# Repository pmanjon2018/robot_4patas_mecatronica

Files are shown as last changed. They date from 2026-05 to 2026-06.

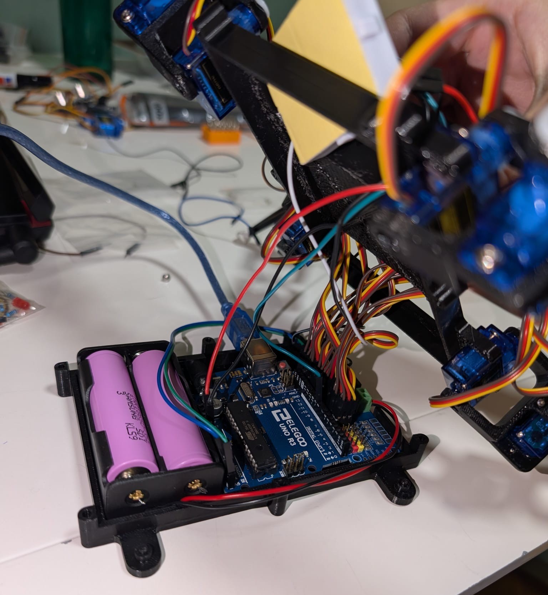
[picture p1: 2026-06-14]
Media/Fotos/MontajeVistaInteriorV2.JPG

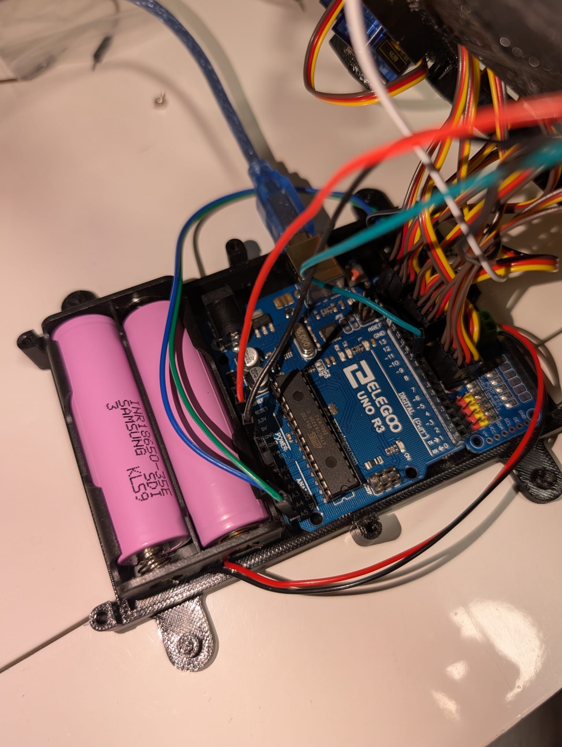
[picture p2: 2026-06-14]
Media/Fotos/MontajeInteriorPines.JPG

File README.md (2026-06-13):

# Robot Cuadrúpedo Autónomo 🤖

Este repositorio contiene la documentación técnica y el código fuente del proyecto final de **Robot con Patas** para la asignatura de **Mecatrónica**. En este trabajo se ha diseñado, fabricado, programado y validado experimentalmente un robot cuadrúpedo capaz de desplazarse de forma estable, transportar carga útil, realizar el seguimiento continuo de una pared y navegar autónomamente evadiendo obstáculos del entorno.

---

## 📋 Índice
1. [Descripción General](#-descripción-general)
2. [Objetivos Cumplidos](#-objetivos-cumplidos)
3. [Restricciones de Diseño](#-restricciones-de-diseño)
4. [Diseño y Arquitectura del Sistema](#-diseño-y-arquitectura-del-sistema)
5. [Problemas Encontrados y Soluciones Adoptadas](#-problemas-encontrados-y-soluciones-adoptadas)
6. [Modos de Funcionamiento](#-modos-de-funcionamiento)
7. [Pruebas de Validación y Criterios de Éxito](#-pruebas-de-validación-y-criterios-de-éxito)
8. [Estructura del Repositorio](#%EF%B8%8F-estructura-del-repositorio)
9. [Documentación Adjunta](#-documentación-adjunta)

---

## 🔍 Descripción General

El propósito central de este proyecto ha sido el desarrollo integral de un **robot con patas completamente funcional**, unificando conceptos avanzados de diseño mecánico, electrónica de control, programación embebida en tiempo real, sistemas de alimentación autónoma y verificación empírica.

La elección de una configuración **cuadrúpeda** responde a un compromiso de ingeniería: proporciona un equilibrio óptimo entre estabilidad estática y dinámica, control de la complejidad mecánica y versatilidad de maniobra en entornos donde los robots con ruedas presentan limitaciones. El resultado es un prototipo robótico autónomo, desvinculado de conexiones umbilicales de alimentación, dotado de una estructura de fabricación propia y una interfaz hombre-máquina (HMI) básica para la gestión segura del encendido y apagado del sistema.

---

## 🎯 Objetivos Cumplidos

A lo largo del desarrollo del proyecto, se lograron satisfacer satisfactoriamente los siguientes objetivos funcionales e hitos de ingeniería:

- [x] **Diseño y construcción:** Estructura física robusta, ligera y balanceada para un robot cuadrúpedo.
- [x] **Integración mecatrónica:** Acoplamiento óptimo de actuadores, sensórica de distancia, electrónica de control y sistemas de potencia.
- [x] **Locomoción guiada:** Implementación de algoritmos de marcha estables para el desplazamiento paralelo respecto a una pared de referencia.
- [x] **Capacidad de carga:** Capacidad probada de transporte de una carga muerta de **250 g** sobre una sección útil especificada de **5 cm x 5 cm**.
- [x] **Navegación inteligente:** Desarrollo de una lógica reactiva y autónoma para la evasión de obstáculos en tiempo real.
- [x] **Validación empírica:** Superación exitosa de pruebas experimentales en escenarios físicos controlados.

---

## ⚙️ Restricciones de Diseño

El prototipo final se consolidó respetando estrictamente el marco de restricciones técnicas y operativas del proyecto:

| Criterio | Restricción / Especificación Técnica |
| :--- | :--- |
| **Dimensiones Máximas** | Envolvente cúbica máxima de 30 cm de alto, 30 cm de ancho y 30 cm de profundidad. |
| **Alimentación** | 100% autónoma a bordo, implementada mediante el uso de baterías recargables. |
| **Aislamiento Eléctrico** | Ausencia absoluta de cables de alimentación o control externos hacia el entorno durante las pruebas. |
| **Estructura Portante** | Chasis y patas de fabricación propia, justificados técnicamente mediante selección de materiales y análisis funcional. |
| **Componentes Comerciales** | Permitidos exclusivamente para elementos genéricos de sensórica, actuación y placas de control. |
| **Interfaz de Usuario** | Inclusión obligatoria de un mecanismo básico de hardware para el arranque y la parada segura. |

---

## 🛠️ Diseño y Arquitectura del Sistema

El diseño mecánico de partida se basó en un modelo open source publicado en Thingiverse, concretamente el proyecto **“Spider robot (quad robot, quadruped)”**, un robot cuadrúpedo impreso en 3D y alimentado mediante Arduino [web:1]. A partir de esta referencia, se adaptaron distintos componentes con **Blender** para ajustarlos a los requisitos geométricos, estructurales y funcionales del proyecto [web:1].

Para simplificar las fases de diseño, manufactura y posterior integración mecatrónica, el robot se estructuró modularmente en los siguientes seis subsistemas interactuantes:

### 1. Estructura Mecánica
- **Componentes:** Chasis principal, soportes estructurales y eslabones de las patas.
- **Detalles:** Diseñados a medida y fabricados específicamente para este proyecto, optimizando la relación rigidez-peso y protegiendo los componentes electrónicos internos.

### 2. Sistema de Actuación
- **Componentes:** Servomotores o actuadores de alto torque distribuidos en las extremidades.
- **Detalles:** Responsables de ejecutar los patrones cinemáticos de las patas para la generación de la marcha (*gait*) y el mantenimiento del equilibrio dinámico.

### 3. Sensórica
- **Componentes:** Sensores de distancia y proximidad, como ultrasonido, infrarrojo o ToF.
- **Detalles:** Dispuestos para la detección lateral de paredes, el control de distancia en paralelo y la detección frontal de obstáculos en la trayectoria.

### 4. Control Embebido
- **Componentes:** Unidad de procesamiento central basada en microcontrolador o tarjeta de desarrollo embebida.
- **Detalles:** Encargada de la lógica de control en tiempo real, procesamiento de señales de sensores, coordinación de actuadores y gestión del comportamiento autónomo.

### 5. Alimentación y Potencia
- **Componentes:** Sistema de baterías recargables con pilas de 3.7V para la distribución de energía.
- **Detalles:** Garantiza el suministro estable del sistema, separando en la medida de lo posible la electrónica de control de la etapa de potencia de los motores.

### 6. Interfaz de Usuario
- **Componentes:** Botones físicos de interacción rápida y elementos visuales o sonoros de estado, como LEDs de diagnóstico.
- **Detalles:** Permite al operador inicializar las rutinas autónomas o inducir una parada controlada de forma inmediata.

> 💡 **Nota de ingeniería:** Esta división modular facilitó significativamente las tareas independientes de prueba, calibración de sensores, mantenimiento mecánico y aislamiento de errores de software y hardware.

---

## 🔧 Problemas Encontrados y Soluciones Adoptadas

Durante el desarrollo e integración del robot surgieron diversas incidencias mecánicas, electrónicas y de fabricación. La resolución de estos problemas fue fundamental para lograr una plataforma funcional y suficientemente robusta para las pruebas finales.

### 1. Problemas con las pilas recargables
Inicialmente se adquirieron pilas recargables que no incluían un cargador compatible, lo que impidió su uso inmediato en la fase de alimentación autónoma del sistema. Como solución, fue necesario comprar nuevas unidades y reorganizar temporalmente la estrategia de alimentación para continuar con el desarrollo.

### 2. Sensor de ultrasonidos averiado
Uno de los sensores de ultrasonidos dejó de funcionar correctamente durante la fase de integración, afectando a la fiabilidad de la detección de distancias. Para resolver esta incidencia, se sustituyó el sensor defectuoso y se recalibraron las lecturas del sistema.

### 3. Limitaciones en la impresión 3D
En una de las iteraciones de fabricación, algunas piezas impresas resultaron más pequeñas de lo esperado, lo que provocó problemas de acoplamiento y montaje. La solución consistió en revisar las dimensiones del diseño, modificar las medidas del modelo y volver a imprimir las piezas corregidas.

### 4. Mejora del giro en las articulaciones
Durante las pruebas se observó que ciertas articulaciones no giraban con la suavidad deseada, afectando a la calidad de la marcha. Para mejorar este comportamiento, se llevó a cabo una limpieza de los motores y un engrase de las zonas mecánicas con mayor fricción.

### 5. Motores averiados
Algunos motores se deterioraron o dejaron de responder correctamente tras varias sesiones de prueba. Fue necesario identificar las unidades dañadas, sustituirlas y volver a verificar el comportamiento de las patas afectadas.

### 6. Riesgo eléctrico por pilas defectuosas
En una fase del montaje, unas pilas defectuosas provocaron una situación de riesgo que estuvo cerca de dañar el Arduino. A partir de este incidente, se revisó completamente la alimentación del sistema, comprobando tensiones, conexiones y el estado real de las baterías antes de realizar nuevas pruebas.

### 7. Propuesta de mejora futura
Como mejora de diseño para futuras versiones, se plantea rediseñar el compartimento de alimentación para que las pilas sean más fáciles de extraer y sustituir. Esta modificación simplificaría el mantenimiento, la recarga y la seguridad general del sistema.

> 💡 **Lección de ingeniería:** Las incidencias encontradas pusieron de manifiesto la importancia de validar por separado la fabricación mecánica, la fiabilidad de la sensórica, el estado de los actuadores y la seguridad eléctrica antes de realizar ensayos completos del robot.

---

## 🕹️ Modos de Funcionamiento

El comportamiento global del robot está regido por una **Máquina de Estados Finitos (FSM)** programada para priorizar la estabilidad de la marcha, la seguridad del sistema y la repetibilidad del movimiento.

### Estados principales del sistema

- **Estado de reposo / espera:** El robot permanece detenido hasta recibir la orden de inicio mediante la interfaz física.
- **Estado de avance:** El robot ejecuta la marcha programada para desplazarse de forma controlada.
- **Estado de seguimiento de pared:** El sistema utiliza la sensórica lateral para mantener una distancia aproximadamente constante respecto a una pared de referencia.
- **Estado de detección de obstáculo:** Cuando se detecta un obstáculo en la trayectoria, se interrumpe el comportamiento de avance normal.
- **Estado de evasión:** El robot ejecuta una maniobra correctiva para esquivar el obstáculo y recuperar una trayectoria válida.
- **Estado de parada segura:** Ante una orden del usuario o una condición crítica, el sistema detiene progresivamente los actuadores para evitar movimientos bruscos o daños mecánicos.

### Lógica general de operación

La FSM se diseñó con una filosofía reactiva, permitiendo cambiar entre estados en función de las lecturas de los sensores y de las condiciones del entorno. Este enfoque facilita una implementación clara, depurable y adecuada para sistemas embebidos con recursos limitados.

---

## ✅ Pruebas de Validación y Criterios de Éxito

Con el fin de verificar el cumplimiento de los objetivos del proyecto, se realizaron diferentes pruebas experimentales sobre el prototipo final.

### 1. Prueba de desplazamiento estable
Se comprobó la capacidad del robot para avanzar de forma continua sin pérdidas significativas de equilibrio ni bloqueos mecánicos en las articulaciones.

### 2. Prueba de seguimiento de pared
Se validó el funcionamiento del sistema de sensórica lateral y del algoritmo de control asociado, verificando que el robot fuese capaz de desplazarse manteniendo una referencia lateral razonablemente constante.

### 3. Prueba de evasión de obstáculos
Se evaluó la respuesta del robot ante la presencia de obstáculos en su trayectoria, comprobando que detectaba el objeto y ejecutaba una maniobra correctiva sin intervención externa.

### 4. Prueba de carga útil
Se verificó que el robot era capaz de transportar una masa de **250 g** distribuida sobre una superficie útil de **5 cm x 5 cm**, manteniendo un comportamiento aceptable durante el desplazamiento.

### 5. Prueba de autonomía funcional
Se comprobó que el sistema era capaz de operar alimentado exclusivamente por baterías, sin depender de cables externos durante la ejecución de las pruebas.

### Criterios de éxito
Se consideró que la validación del sistema era satisfactoria cuando el robot:
- Se desplazaba de forma estable.
- Mantenía el seguimiento de pared.
- Detectaba y evitaba obstáculos.
- Soportaba la carga útil especificada.
- Funcionaba de forma autónoma con alimentación embarcada.

---

## 🗂️ Estructura del Repositorio

La organización del repositorio se ha planteado para separar claramente el código, la documentación y los recursos de diseño:

```bash
.
├── README.md
├── docs/
│   ├── memoria.pdf
│   ├── esquemas/
│   └── pruebas/
├── firmware/
│   ├── main.ino
│   ├── sensores/
│   ├── actuadores/
│   └── control/
├── hardware/
│   ├── diseno_3d/
│   ├── esquemas_electricos/
│   └── lista_componentes/
└── media/
    ├── imagenes/
    └── videos/
```

> **Nota:** La estructura exacta puede adaptarse en función de la evolución del proyecto y del material finalmente incorporado al repositorio.

---

## 📎 Documentación Adjunta

Este repositorio puede incluir la siguiente documentación complementaria para reforzar la trazabilidad técnica del proyecto:

- Memoria técnica completa del sistema.
- Planos, modelos y modificaciones de las piezas impresas en 3D.
- Esquemas eléctricos y de alimentación.
- Código fuente del control embebido.
- Fotografías del montaje final.
- Evidencias experimentales en vídeo o capturas de las pruebas realizadas.

---

## 👨‍🔧 Autor

Proyecto desarrollado como trabajo final para la asignatura de **Mecatrónica**, orientado al diseño, construcción, integración y validación de un **robot cuadrúpedo autónomo**.

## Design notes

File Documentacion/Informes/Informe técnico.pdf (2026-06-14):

# Informe técnico

## Índice

1. Diseño Conceptual
1.1. Definición del Problema y Objetivos
1.2. Alternativas de Locomoción y Justificación Cinemática
1.3. Materiales y Especificaciones Geométricas
1.4. Análisis Inicial de Viabilidad Física (Carga y Torque)
1.5. Arquitectura del Sistema (Cajas Negras)
2. Diseño Detallado
2.1. Arquitectura de Hardware y Mapeo de Pines
2.2. Aislamiento y Gestión de Energía (Tolerancia a Fallos)
2.3. Estabilidad Estática y Centro de Gravedad
3. Fabricación e Integración
3.1. Fabricación Aditiva y Ensamblaje Mecánico
3.2. Gestión de Riesgos y Resolución de Problemas (Troubleshooting)
3.3. Análisis de Costes (Presupuesto)
4. Programación y Simulación
4.1. Gemelo Digital y Simulación Cinemática (PyBullet)
4.2. Arquitectura de Software y Máquina de Estados
4.3. Algoritmo de Locomoción (Trot Gait)
4.4. Navegación Autónoma y Evasión de Obstáculos
4.4. Fase 2: Desarrollo y Propuesta de Navegación Autónoma

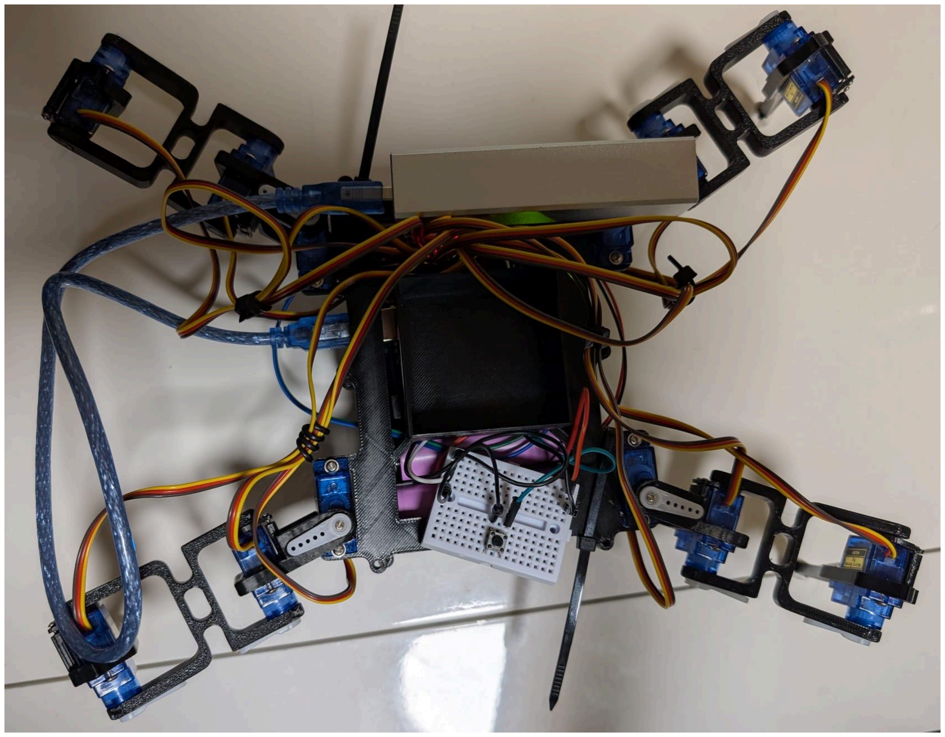
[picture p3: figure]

## 1. Diseño Conceptual

### 1.1. Definición del Problema y Objetivos

El objetivo fundamental del proyecto consiste en el diseño, desarrollo e integración de un sistema robótico cuadrúpedo completamente autónomo. El sistema debe resolver dos tareas operativas principales establecidas en los requerimientos:

1. Desplazamiento con carga: El robot debe desplazarse paralelo a una pared plana por al menos 1 metro de distancia en un tiempo máximo de 1 minuto. Durante esta tarea, debe transportar de manera estable una carga de 250 gramos ubicada en un área central específica de 5 cm x 5 cm sobre su estructura.
2. Evasión y Autonomía: El sistema debe navegar de forma autónoma esquivando obstáculos de 10x10 centímetros dentro de un área de 2 metros cuadrados, alcanzando cada una de las paredes colindantes partiendo desde el centro, en un tiempo máximo de 2 minutos.

### 1.2. Alternativas de Locomoción y Justificación Cinemática

Para cumplir con los criterios de estabilidad exigidos, se descartó el uso de ruedas o tracción por orugas en favor de un diseño biomimético de cuatro patas. Aunque la marcha básica de un cuadrúpedo puede lograrse con 8 grados de libertad (DOF), en este proyecto se ha optado por una arquitectura superior de 12 DOF (tres servomotores MG90S por pata: Coxa, Fémur y Tibia).

Esta decisión de diseño se justifica por tres ventajas mecánicas críticas para el éxito de la práctica:

- Gestión de la Carga Útil: Permite una mejor distribución del centro de masas y un control dinámico superior al transportar los 250 gramos de peso extra exigidos, manteniendo el polígono de sustentación.
- Eficiencia de Marcha: Facilita la implementación de un paso de trote coordinado, incrementando la velocidad para cumplir con las restricciones de tiempo establecidas.
- Evasión Activa: El motor de la cadera (Coxa) otorga al sistema la capacidad de pivotar y rotar sobre su propio eje central, un movimiento indispensable para la fase de evasión de obstáculos sin necesidad de arrastrar las extremidades.

### 1.3. Materiales y Especificaciones Geométricas

La estructura física del robot ha sido diseñada basándome en el conocido y pionero modelo de RegisHsu, pero adaptándolo de forma propia mediante software de modelado 3D: Blender + Phobos. No quería reinventar la rueda, sino ser práctica, aprender y aplicar los conocimientos adquiridos a lo largo de la carrera. Conservé el diseño de las patas y adapté el diseño del chasis a mis componentes y necesidades, como:

- Cerrar el agujero de la base del chasis
- Añadir una caja de carga para la masa de 5x5cm reforzada por debajo
- Cambiar el agujero de carga del arduino, pero no me fue útil porque decidí girarlo posteriormente.

- Redimensionar ambas partes del chasis para que entren mis componentes.

Las piezas estructurales (chasis y eslabones de las extremidades) están fabricadas en polímero PLA impreso en 3D, material que ofrece un equilibrio óptimo entre rigidez mecánica y ligereza.

El sistema presenta una envolvente compacta que cumple estrictamente con la restricción de no superar los 30 cm en ninguna de sus dimensiones:

- Cuerpo central (Chasis + Actuadores base): 13,5 cm de longitud x 12 cm de anchura x 3,3 cm de altura.
- Extremidades: Longitud máxima de extensión teórica de 16 cm. Altura nominal operativa de 10 cm con las articulaciones en ángulo recto (90°).

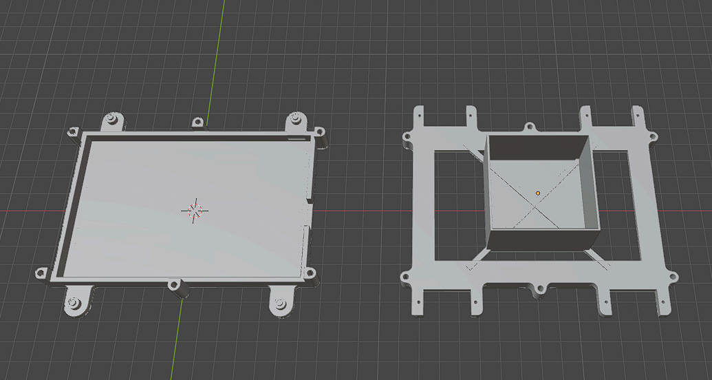
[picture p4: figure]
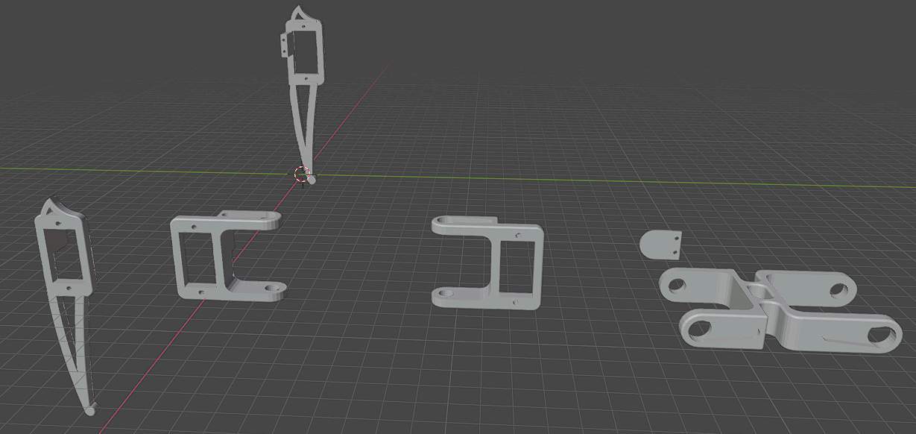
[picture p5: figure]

Figura 1: Diseño y componentes estructurales propios impresos en PLA.

### 1.4. Análisis Inicial de Viabilidad Física (Carga y Torque)

Tomando como base las especificaciones geométricas y el material seleccionado, se ha realizado un cálculo teórico de viabilidad de los actuadores (servomotores MG90S). El sistema completo es alimentado por baterías recargables, concretamente dos pilas 18650 de Litio que entregan una tensión nominal de 7.4V.

Estimando un brazo de palanca operativo de 5 cm (distancia desde el eje de articulación hasta el punto de apoyo en el suelo), cada pata tiene una capacidad teórica de elevación de aproximadamente 440 gramos. Durante un paso de trote, donde dos patas sostienen el peso total, la fuerza combinada es de 880 gramos. Considerando que la masa total estimada del sistema (chasis, baterías independientes, electrónica y el lastre obligatorio de 250 gramos) ronda los 800 gramos (exactamente 785 gramos), el diseño demuestra ser viable a nivel mecánico.

Posteriormente decidí que era mejor mover una pata por vez, lo que lo hace más estable con más peso, más robusto, no es más lento, y llega más lejos en menos tiempo.

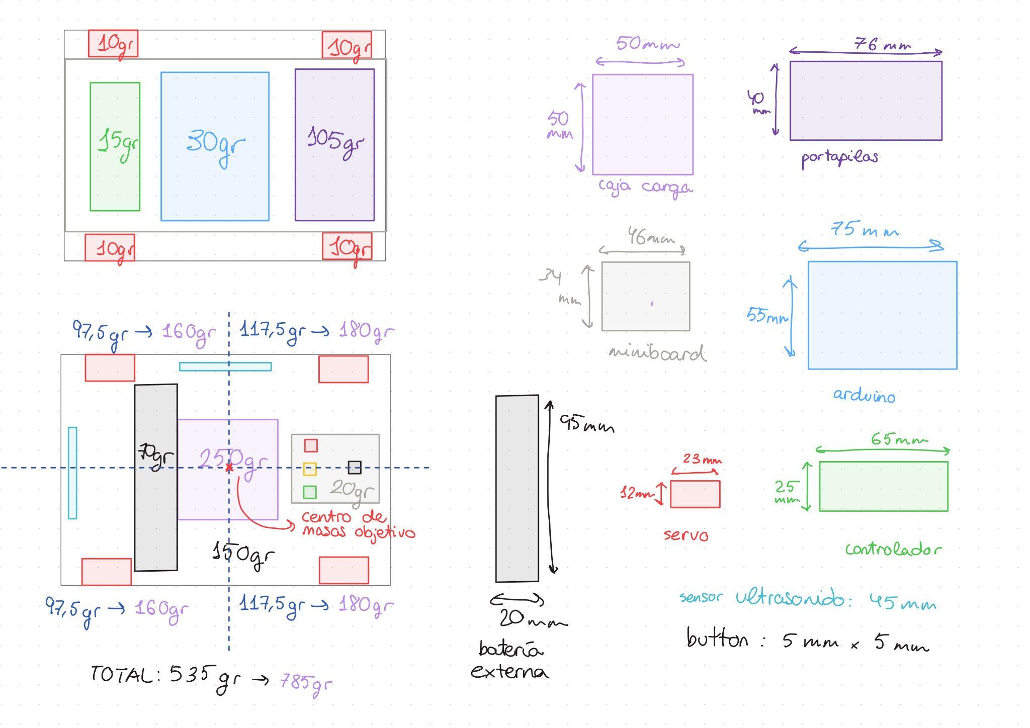
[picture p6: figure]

Figura 2: Boceto conceptual inicial indicando la distribución de masas, ubicación de la carga de 250g y sensores.

### 1.5. Arquitectura del Sistema (Cajas Negras)

El control del cuadrúpedo se divide funcionalmente en módulos interconectados, aislando la potencia de los actuadores de la lógica de control para garantizar la estabilidad eléctrica. Además, se integra una interfaz de usuario básica mediante pulsador físico e indicadores visuales para iniciar y detener el funcionamiento.

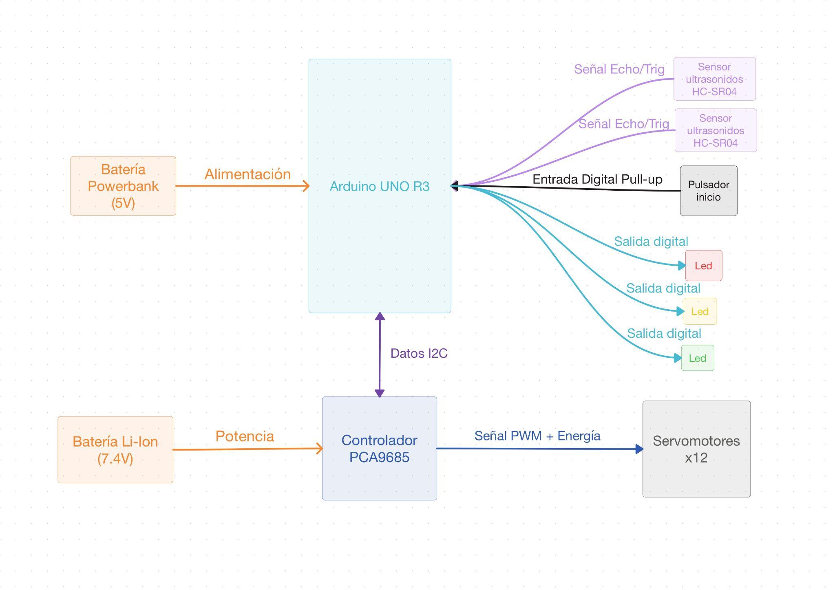
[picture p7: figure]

Figura 3: Diagrama de arquitectura de hardware del sistema.

## 2. Diseño Detallado

### 2.1. Arquitectura de Hardware y Mapeo de Pines

La integración de los componentes electrónicos se ha planificado priorizando la eficiencia del microcontrolador principal (Arduino UNO). Para evitar la saturación de los temporizadores internos del Arduino, se delegó el control de las señales PWM de los 12 motores MG90S a un controlador dedicado PCA9685, el cual se comunica mediante el protocolo I2C utilizando únicamente dos líneas de datos.

El mapeo de conexiones quedó establecido de la siguiente manera:

- Comunicación I2C (PCA9685): Pin analógico A4 (SDA) para los datos y A5 (SCL) para la señal de reloj.
- Sensores Ultrasónicos HC-SR04: Asignado a los pines digitales (uno analógico y uno digital) correspondientes para las señales Trigger y Echo, permitiendo la detección de obstáculos frontales y laterales, apra saber cuando pasamos el obstáculo.
- Interfaz Visual (Semáforo LED): Conectados a pines digitales configurados como salidas (OUTPUT) para indicar los estados de la máquina de estados (Reposo, Marcha, Alerta).
- Pulsador de Inicio/Parada: Conectado a un pin digital configurado por software como INPUT_PULLUP. Esta decisión de diseño permite utilizar la resistencia interna de 20k ohmios del microcontrolador, ahorrando componentes externos en la placa y evitando lecturas erróneas por estados flotantes (ruido eléctrico).

### 2.2. Aislamiento y Gestión de Energía (Tolerancia a Fallos)

Durante la fase inicial de pruebas se detectó una vulnerabilidad crítica: alimentar la lógica de control y la potencia de los actuadores desde una única fuente (baterías Li-Ion de 7.4V pasadas por el pin VIN del Arduino) provocaba picos de consumo masivos al arrancar los 12 motores simultáneamente. Esto causó una caída de tensión severa y sobrecalentó (quemó) el regulador de voltaje interno del microcontrolador, teniendo que comprar otro Arduino.

Aplicando el método científico para la resolución de problemas, la arquitectura final implementa un aislamiento galvánico y energético total:

1. Red de Potencia (Fuerza): El bloque de baterías 18650 (7.4V) se conecta directa y exclusivamente a la bornera de alimentación del PCA9685, entregando todo el amperaje necesario a los motores sin pasar por la placa lógica.
2. Red Lógica (Cerebro): El Arduino y sus sensores periféricos se alimentan de forma completamente independiente mediante un Powerbank de 5V conectado por USB. Esto garantiza que el "cerebro" nunca se apague ni sufra interferencias, sin importar cuánto esfuerzo mecánico estén realizando las patas.

Consideré que este modelo era más estable y mantenible, no corrí más riesgos de los necesarios.

### 2.3. Estabilidad Estática y Centro de Gravedad

Con un peso en vacío de 535 g, la distribución de componentes internos se modeló para alojar el requerimiento de los 250 g de carga extra sin comprometer la locomoción. Es verdad que sobrepasa un poco el peso de la parte posterior frente a la delantera, pero no es tan significante en la práctica. Las baterías 18650 (el componente más pesado del sistema) se han posicionado estratégicamente compensando el peso de la lógica de control, buscando que el Centro de Gravedad (CG) del sistema coincida con el cruce diagonal geométrico de las extremidades. La carga útil de 5x5 cm se asienta directamente sobre la vertical de este CG para prevenir momentos de vuelco hacia atrás durante el levantamiento de las patas delanteras.

## 3. Fabricación e Integración

### 3.1. Fabricación Aditiva y Ensamblaje Mecánico

La materialización del chasis y las extremidades se llevó a cabo mediante técnicas de prototipado rápido (Impresión 3D). Se utilizó un rollo de filamento PLA, consumiendo aproximadamente un 40% del material (equivalente a unos 7-10 € de coste de material neto), tuve que imprimir dos veces por problemas de redimensionamiento.

El ensamblaje mecánico requirió un ajuste fino (lijado) de las tolerancias en las articulaciones para asegurar que los ejes de los servomotores MG90S encajaran firmemente sin generar fricción parasitaria en las extremidades. Todo el cableado de potencia y datos se enrutó por el interior del chasis impreso para evitar enredos durante la marcha cuadrúpeda, pasando por los agujeros superiores que se dejaron en el diseño y proteger las conexiones ante posibles vuelcos.

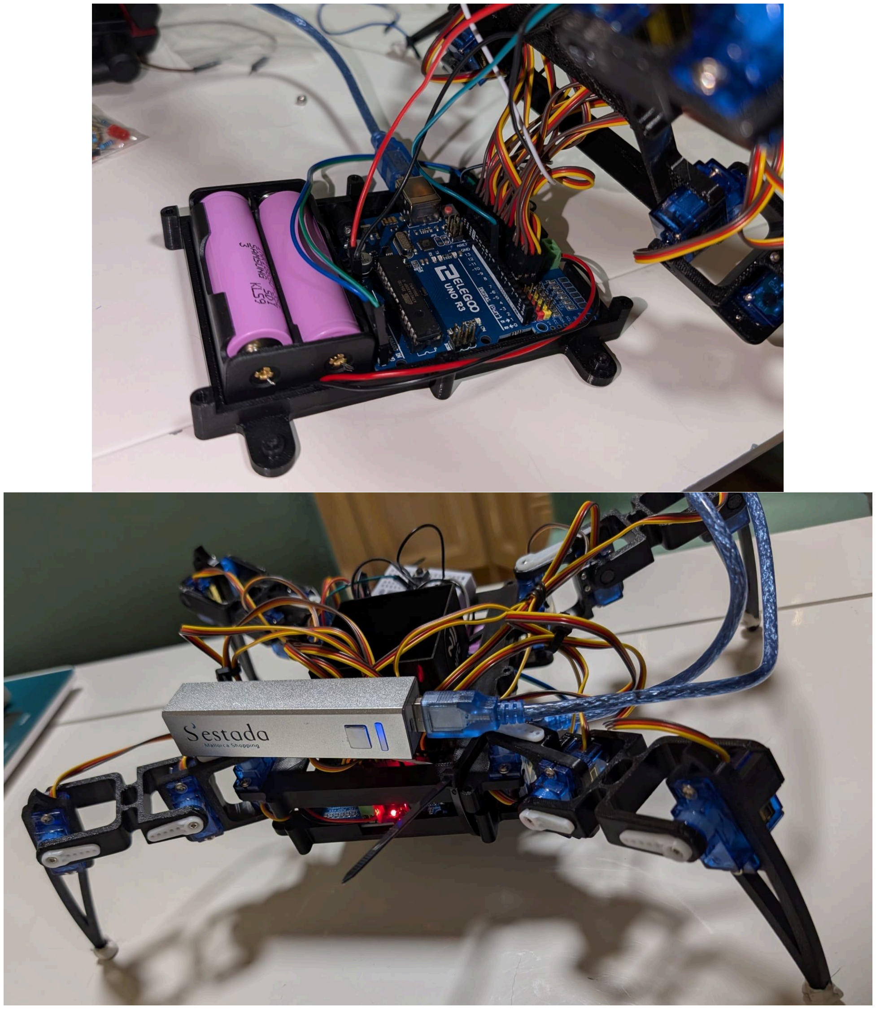
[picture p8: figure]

Figura 4: Integración del hardware en el chasis de PLA, mostrando el
aislamiento de la lógica y la potencia.

### 3.2. Gestión de Riesgos y Resolución de Problemas (Troubleshooting)

Durante la fase de integración física y primeras pruebas de estrés, el sistema sufrió varias contingencias propias del desarrollo de hardware en el mundo real, las cuales fueron documentadas y solventadas:

- Fallo de Regulación (Sobretensión): El intento inicial de alimentar la placa lógica y los actuadores simultáneamente con baterías Li-Ion provocó la quema del regulador de voltaje interno del Arduino UNO. Esto derivó en el rediseño inmediato de la arquitectura de energía (explicado en la sección 2.2) y la sustitución de la placa microcontroladora.

- Componentes Defectuosos de Fábrica (DOA): Se detectó un fallo de comunicación I2C derivado de un controlador PCA9685 defectuoso de fábrica, así como lecturas erráticas en uno de los sensores ultrasónicos HC-SR04, procediendo a su reemplazo pero no a tiempo.
- Fatiga Mecánica de Actuadores: El peso del robot (535 g) sumado a la carga útil estática (250 g) y las pruebas de potencia, generó picos de torque que estropearon la piñoneria interna de algunos servomotores durante la fase de calibración de la marcha. Para garantizar la fiabilidad el día de la prueba final, se amplió el margen de repuestos a 18 unidades totales.

### 3.3. Análisis de Costes (Presupuesto)

A continuación, se detalla el Bill of Materials (BOM) del proyecto. Se desglosa el coste ideal teórico del prototipo final frente al coste real de desarrollo, el cual incluye las mermas, repuestos y herramientas de alimentación adquiridas para solventar las incidencias descritas.

Componente | Cantidad Ideal | Coste de Desarrollo (Real) | Notas de Integración
Microcontrolador Arduino UNO | 1 | 7,00 € | Sustitución por quema del regulador original.
Controlador I2C PCA9685 | 1 | 7,00 € | Incluye gestión de 1 unidad defectuosa (devuelta).
Servomotores MG90S | 12 | 24,50 € | Adquisición de 18 uds por rotura mecánica en pruebas.
Sensor Ultrasónico HC-SR04 | 2 | 3,00 € | 3 uds totales adquiridas por defectos de fábrica.
Sistema de Energía Lógica (Powerbank 5V) | 1 | 0,00 € | Material amortizado / Regalo.
Sistema de Energía Potencia (Pilas 18650) | 2 | 50,00 € | Incluye pack de 10 celdas extra y cargador dedicado.
Portapilas 18650 | 1 | 2,00 € | Montaje en chasis central.
Material Estructural (PLA Impresión 3D) | ~150g | 8,50 € | Estimación del porcentaje de rollo de 20€ utilizado.
Componentes Pasivos (LEDs, Botón, Cables) | Varios | 0,00 € | Reutilización de stock de laboratorio / kits previos.
TOTAL PROYECTO REAL | | 102,00 € | Coste asumido para garantizar redundancia y repuestos.

# 4. Programación y Simulación

### 4.1. Gemelo Digital y Simulación Cinemática (PyBullet)

Antes de volcar el código al hardware físico y arriesgar la integridad de los actuadores, se desarrolló un entorno de simulación utilizando el motor de físicas PyBullet en Python. Se generó un archivo URDF (Unified Robot Description Format) modelando las masas exactas del chasis, las baterías y la carga útil de 250 g.

Para validar la viabilidad mecánica, se limitó la fuerza de las articulaciones virtuales a 0.215 N·m (el equivalente físico del torque máximo de los motores MG90S operando a 6-7V). La simulación confirmó que, implementando una marcha de trote, el robot es capaz de levantar la carga sin colapsar, amortiguando correctamente el impacto contra el suelo virtual.

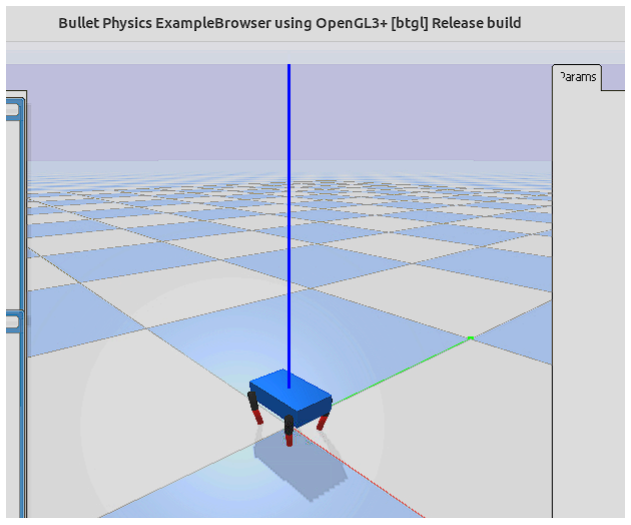
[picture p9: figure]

Figura 5: Simulación física del cuadrúpedo en PyBullet analizando el reparto de masas y límites de torque.

### 4.2. Arquitectura de Software y Máquina de Estados

El código del microcontrolador Arduino ha sido estructurado mediante una Máquina de Estados Finitos (FSM) no bloqueante. Esto permite que el robot pueda leer sensores y mover las patas al mismo tiempo sin quedarse "congelado" esperando una instrucción.

El sistema se divide en tres estados principales, indicados visualmente por el semáforo LED:

1. Estado de Reposo (LED Verde): Al pulsar el botón, el robot inicializa los 12 motores en su posición de 90 grados y entra en bucle de espera. Se aplica un sistema antirrebotes (debounce) por software de 250 ms en el pulsador para evitar lecturas falsas al iniciar la marcha.
2. Estado de Marcha (LED Verde): Al pulsar el botón, el robot inicia el desplazamiento autónomo en línea recta y el sensor ultrasónico comienza a emitir pulsos constantes.

3. Estado de Evasión/Parada (LED Amarillo o Rojo): Interrupción del ciclo de marcha dictada por la retroalimentación del entorno, si es un obstáculo evitable, el led se iluminará en amarillo, si es la pared, se iluminará en rojo.

### 4.3. Fase 1: Algoritmo básico de Locomoción

Para cumplir con el requisito de desplazamiento en línea recta transportando carga, se programó una cinemática de marcha tipo "Trote" (Trot Gait). En este ciclo, el robot mueve sus patas en pares diagonales (ej. delantera izquierda y trasera derecha simultáneamente). Este método garantiza que el Centro de Gravedad siempre se mantenga dentro del polígono de sustentación formado por las otras dos patas que permanecen en el suelo, maximizando la estabilidad durante el transporte de los 250 g.

### 4.4. Fase 2: Desarrollo y Propuesta de Navegación Autónoma

El enfoque principal y la validación empírica de este proyecto se han centrado en garantizar el éxito de la primera fase del requerimiento: la estabilidad mecánica y el desplazamiento continuo soportando la carga útil de 250 gramos.

No obstante, la arquitectura de software (Máquina de Estados) ha sido diseñada desde cero para soportar la Fase 2 (Evasión de Obstáculos). El código entregado en los anexos incluye la lógica de integración de los sensores ultrasónicos HC-SR04. La cinemática programada establece que, al detectar un obstáculo, el sistema interrumpa el trote y active un pivote lateral usando los actuadores de las Coxas. Debido a las incidencias de hardware con las lecturas erráticas de los sensores ultrasónicos iniciales y las limitaciones de tiempo físico para una calibración empírica segura, esta segunda fase se presenta a nivel de código y diseño conceptual, priorizando para la demostración física la robustez del requerimiento de carga.

# 5. Bibliografía

https://regishsu.blogspot.com/2015/07/robot-quadruped-robot-re-design-3-round.htmlhttps://www.thingiverse.com/thing:1009659https://www.instructables.com/DIY-Spider-R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

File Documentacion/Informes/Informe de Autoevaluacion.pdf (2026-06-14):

Grupo: Rocky

## Informe de Autoevaluación Individual

### 1. Reflexión sobre el Desarrollo Técnico

El desarrollo de este proyecto ha supuesto un reto de ingeniería multidisciplinar asumido de forma íntegramente individual. Esto ha puesto a prueba mi capacidad de resolución de problemas bajo presión en todas las áreas del diseño: modelado, impresión, electrónica y programación.

Inicialmente, sobreestimé la capacidad de diseño de otras personas, como fue coger el modelo pionero en cuadrúpedos de RegisHsu, en el cual confíe en su diseño de patas en 3 direcciones como hemos visto en varias asignaturas, que se ha replicado con leves modificaciones, pero que no es tan exacto para servomotores SG90, por lo que tuve que lijar las piezas de la cadera para que los motores pudiesen girar correctamente.

También subestimé el consumo eléctrico de 12 motores MG90S operando simultáneamente. Esto derivó en la necesidad de un cargador de pilas.

Además, al intentar hacerlo autónomo, el voltaje de las baterías directamente conectados al arduino que técnicamente tenía un regulador de entre 7.2V y 12V a 5V no funcionó, lo que derivó en un fallo crítico de hardware: sobrecalentamiento del regulador de voltaje, el cual se fundió, lo que me obligó a aplicar el método científico, aislar el problema y rediseñar la arquitectura hacia un sistema de energía de doble fuente, en este caso con una powerbank que no fuese muy pesada que le diese 5V por USB.

Esta crisis fue mi mayor aprendizaje: comprender la diferencia entre la teoría de un circuito en papel y la realidad física de la corriente.

### 2. Resiliencia Mecánica y Gestión del Alcance

A lo largo de las pruebas, tuve que hacer frente a la fatiga de los componentes, llegando a abrir y reparar manualmente la piñonería interna de los servomotores para no paralizar el desarrollo.

Asimismo, ante la recepción de sensores ultrasónicos defectuosos, tomé una decisión analítica de gestión de proyecto: congelar el alcance de la Fase 2 (Navegación Autónoma) para asegurar la Fase 1. Prioricé entregar un sistema físico robusto, capaz de transportar la carga con estabilidad, dejando la evasión de obstáculos implementada a nivel de código como una arquitectura preparada para el futuro.

### 3. Valoración Final

Considero que el resultado final es un éxito a nivel de diseño de sistemas. He logrado construir un gemelo digital en PyBullet para validar cálculos de torque, diseñar la estructura 3D basándome en otras que ya existían (no reinventar la rueda) y montar un hardware tolerante a fallos de forma autónoma. El proyecto demuestra madurez técnica, capacidad de reparación in-situ y una gestión de riesgos realista.

Como conclusión, me he encargado yo sola de hacer todo el proyecto. Ha sido un desafío, pero he aprendido mucho.

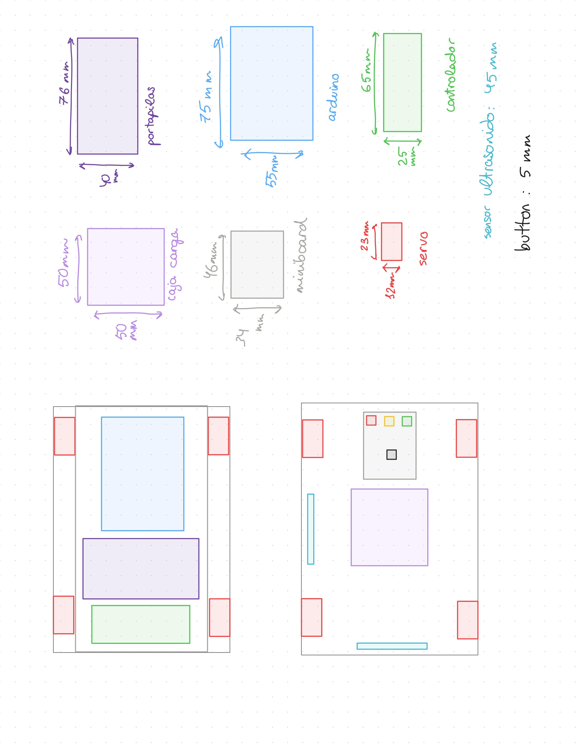
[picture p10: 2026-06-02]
Media/Fotos/ConceptRobot-V2.jpg

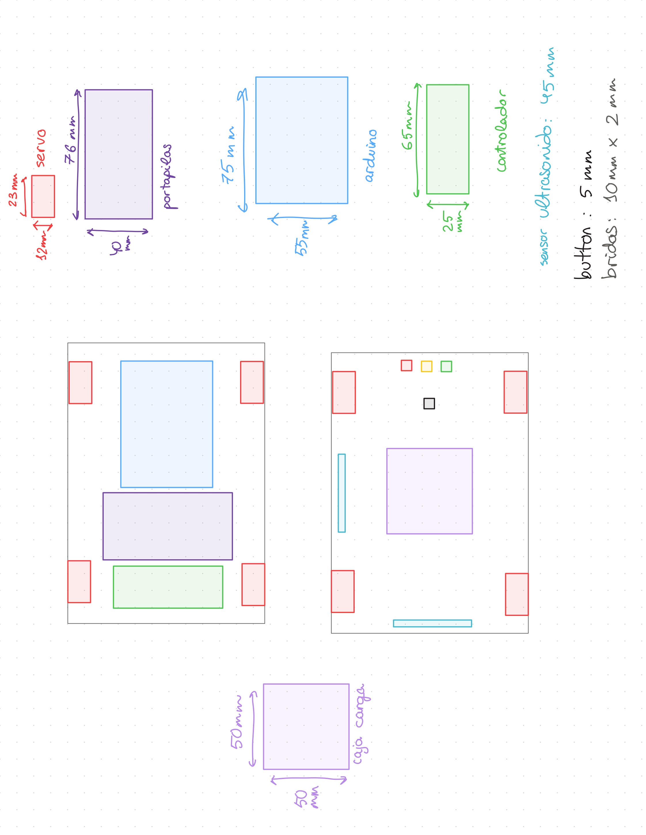
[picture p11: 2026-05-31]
Media/Fotos/ConceptRobot-V1.jpg

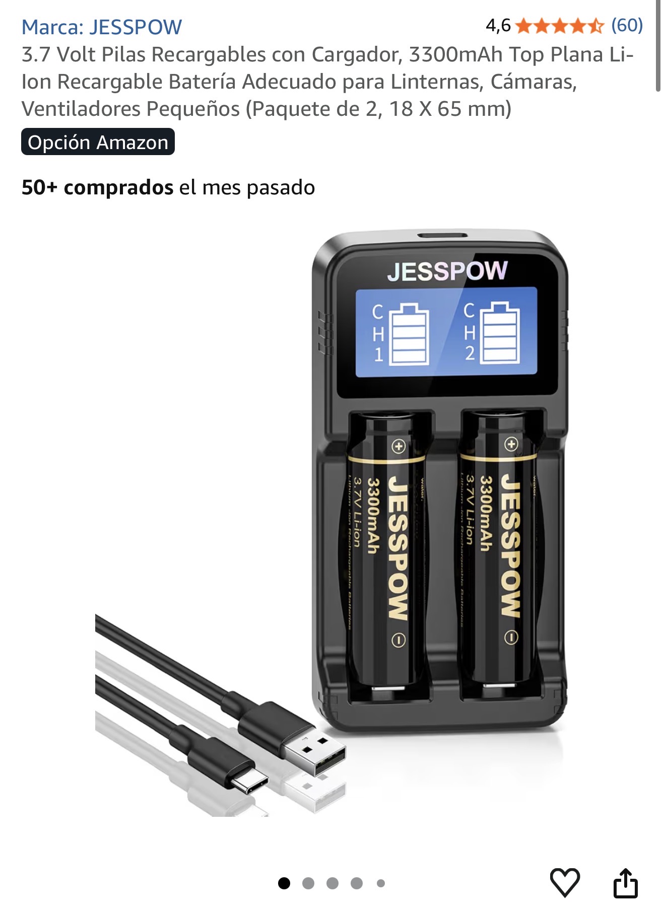
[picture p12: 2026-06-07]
Hardware/Electronica/PortaPilas.jpg

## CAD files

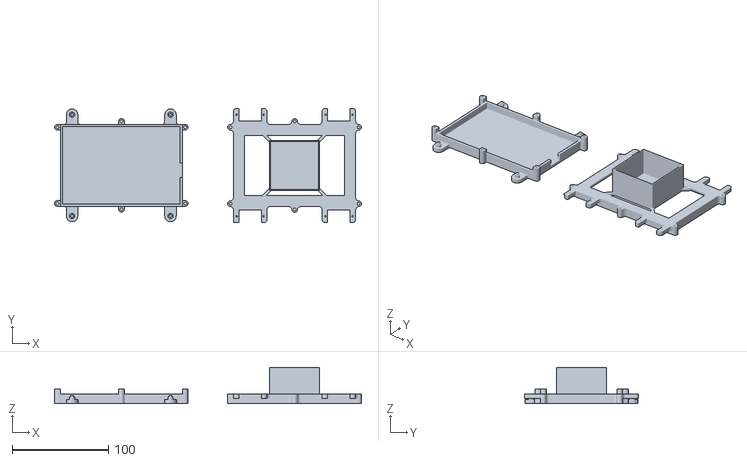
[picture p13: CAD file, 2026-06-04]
Hardware/ArchivosImpresion/body-v2.stl
318.9 x 118.5 x 37.5

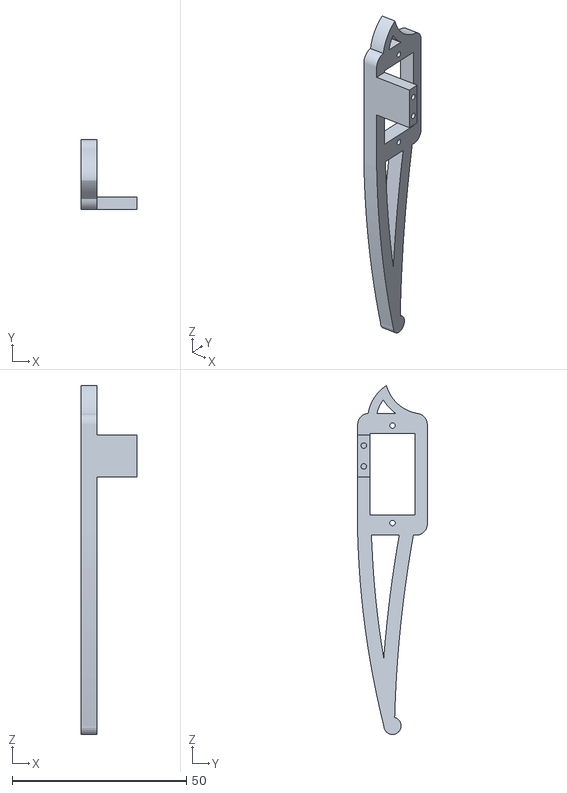
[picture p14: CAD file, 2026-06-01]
Hardware/ArchivosImpresion/tibia_r.stl
16.0 x 20.0 x 100.3

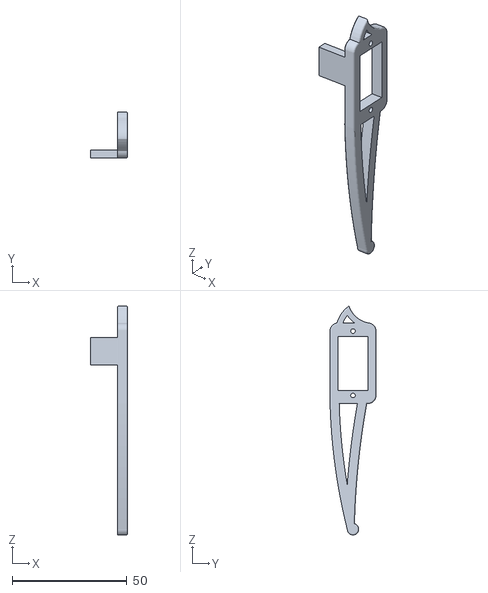
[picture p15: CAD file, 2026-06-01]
Hardware/ArchivosImpresion/tibia_l.stl
16.3 x 20.0 x 99.7

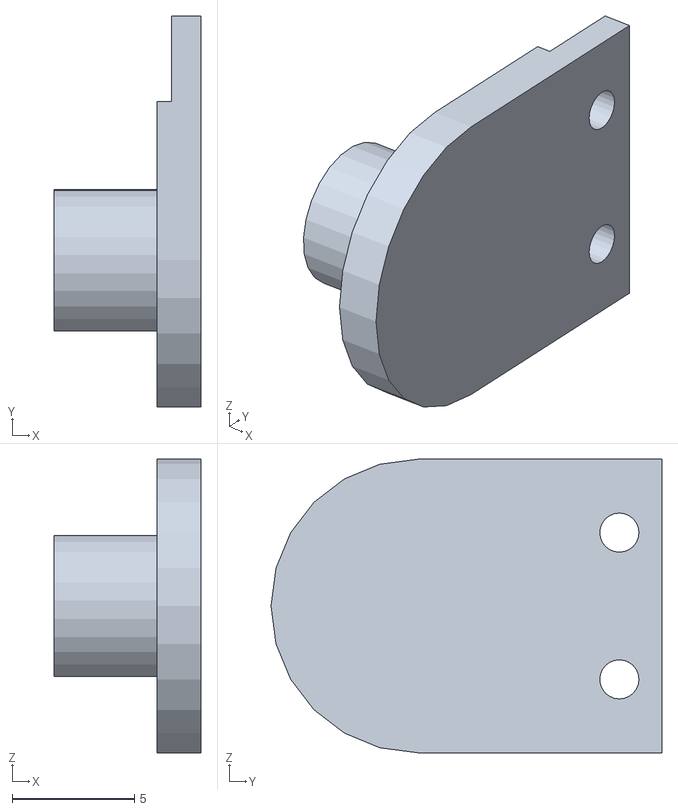
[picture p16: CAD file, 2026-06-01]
Hardware/ArchivosImpresion/s_hold.stl
6.00 x 16.0 x 12.0

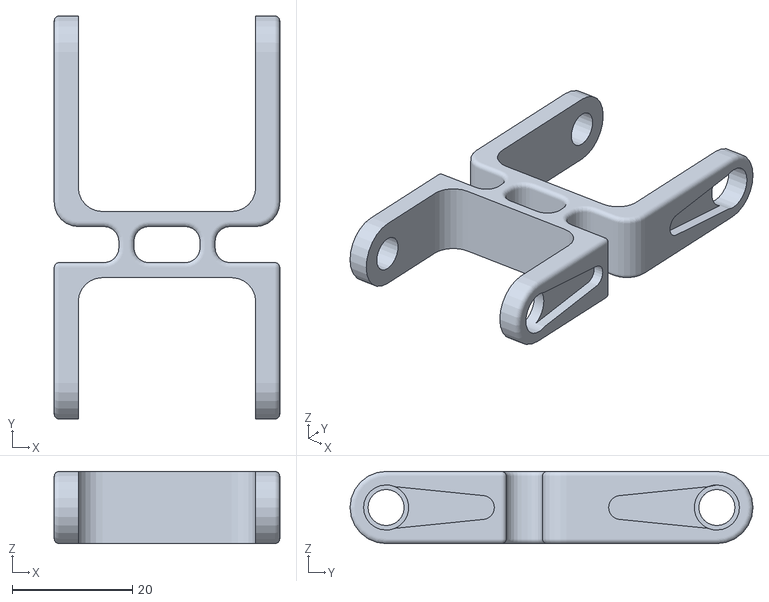
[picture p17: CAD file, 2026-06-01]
Hardware/ArchivosImpresion/femur_1.stl
37.5 x 67.0 x 12.0

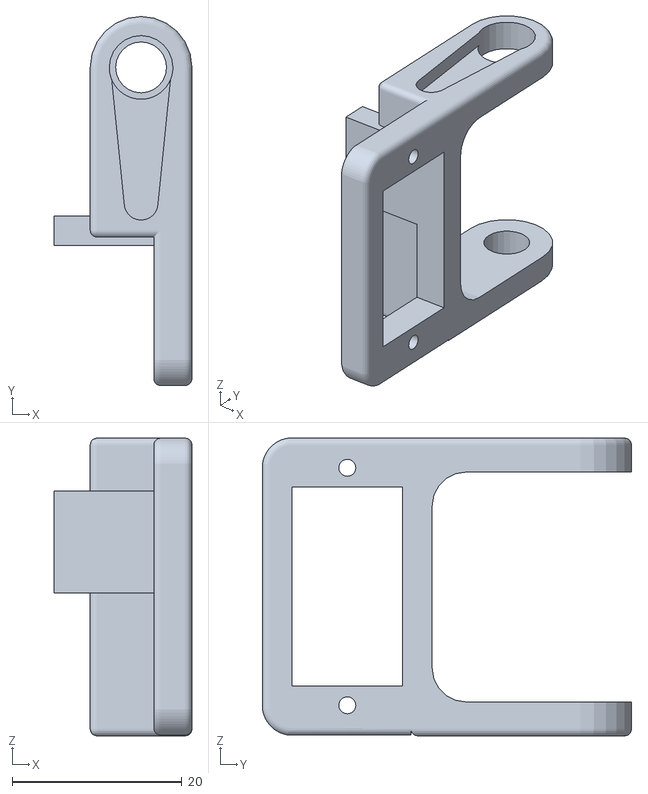
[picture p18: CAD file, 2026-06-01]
Hardware/ArchivosImpresion/coxa_l.stl
16.3 x 43.5 x 35.1

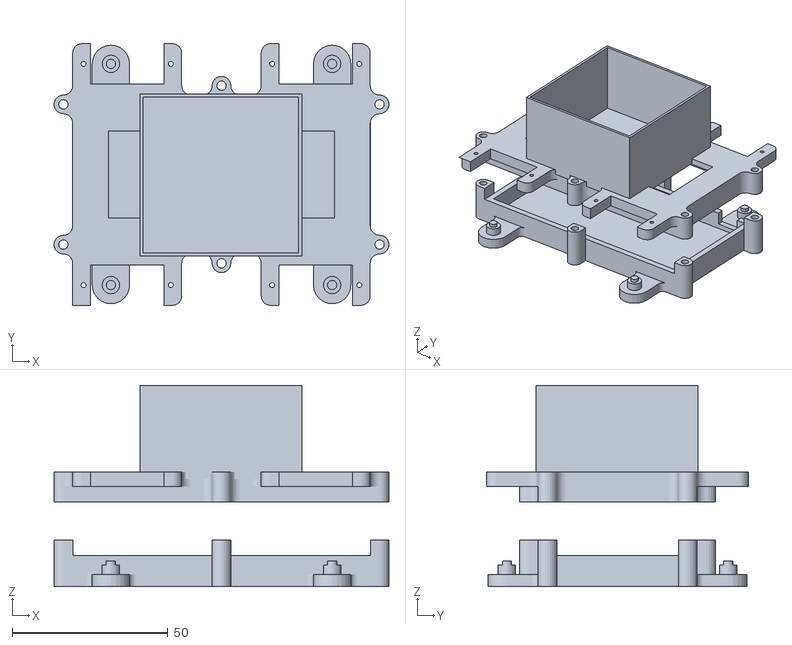
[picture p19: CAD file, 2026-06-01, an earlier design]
Hardware/ArchivosImpresion/body-v1.stl
107.5 x 84.0 x 64.6

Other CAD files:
Hardware/ArchivosImpresion/coxa_r.stl

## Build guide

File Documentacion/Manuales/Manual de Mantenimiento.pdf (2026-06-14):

## Manual de Mantenimiento

El correcto mantenimiento preventivo es vital para alargar la vida útil del hardware, especialmente de los actuadores mecánicos sometidos a estrés por el peso de la carga.

### 1. Mantenimiento Eléctrico (Baterías)

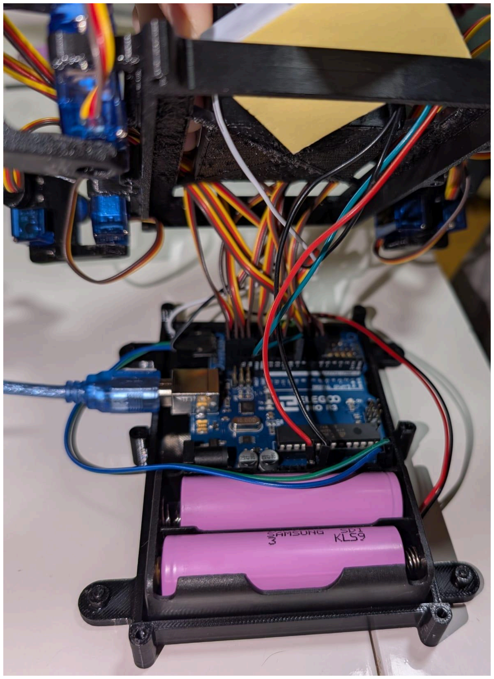
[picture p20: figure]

- Fuentes de Alimentación: El sistema cuenta con dos fuentes de energía totalmente recargables. El Powerbank (5V) se recarga mediante su puerto USB estándar, mientras que las pilas Li-Ion 18650 (7.4V) deben extraerse y recargarse en su base dedicada. Las baterías 18650 no deben descargarse nunca por debajo de los 6.0V en conjunto. Si nota que los motores "tiemblan" o pierden fuerza para levantar el chasis, detenga la acción inmediatamente y ponga a cargar las baterías en su cargador dedicado.*
- Verifique antes de cada uso que no hay cables pelados rozando el chasis de PLA.
- Cargue las pilas y baterías con cargadores oficiales o de calidad.

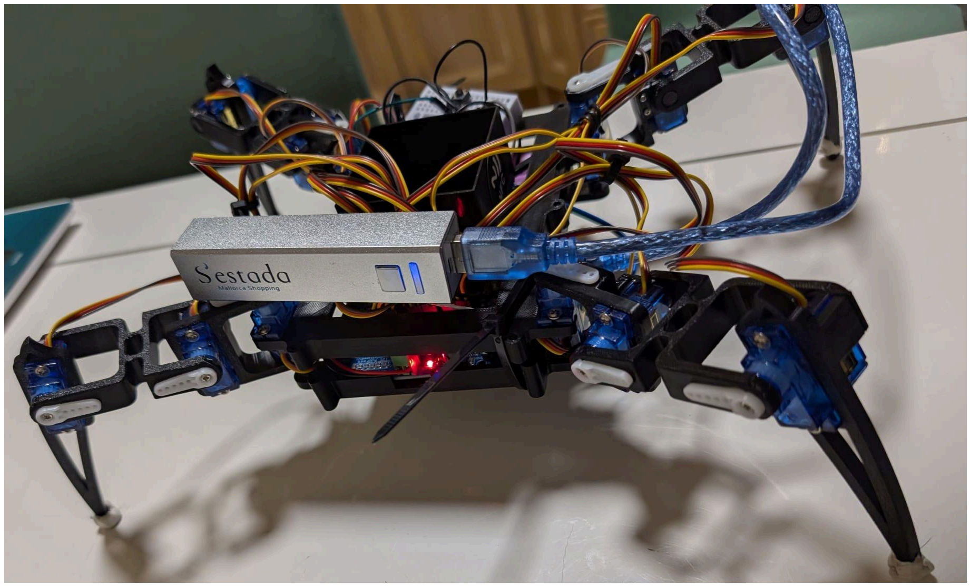
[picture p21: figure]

### 2. Mantenimiento Mecánico (Actuadores y Chasis)

- Revisión de Piñonería: Los servomotores MG90S tienen engranajes plásticos, durante el uso prolongado o al someter al robot a cargas excesivas, es posible que el eje del servomotor MG90S salte, provocando que el engranaje interno más pequeño se salga de su riel. Si con el robot apagado nota que una pata gira libremente sin ofrecer resistencia, no es necesario desechar el motor puede repararlo*.
- Tornillería: Tras 10 minutos de marcha acumulada, las vibraciones del paso de trote pueden aflojar los tornillos de las articulaciones (Coxa, Fémur, Tibia). Revise y apriete suavemente con un destornillador pequeño de estrella antes de cada demostración.
- Integridad del PLA: Inspeccione visualmente las uniones impresas en 3D buscando microfisuras causadas por el estrés de los 250 gramos de carga extra.
- Cableado: Revise que todos los cables estén perfectamente conectados, ninguno fuera de su posición, especialmente los de los pines VCC y GND.
- Sensores/leds: Cada cierto tiempo, conviene revisar si los sensores y leds funcionan correctamente, si no es así, sustituirlos recordando los pines a los que están conectados.
- Sistema de Cierre (Bridas vs. Tornillos): Actualmente, la carcasa superior e inferior del chasis impreso en 3D están unidas mediante bridas de nylon. Esto se ha diseñado así deliberadamente para la fase de prototipado, permitiendo un acceso rápido a las tripas del robot para el cambio frecuente de baterías. El diseño original en PLA cuenta con los orificios calibrados correspondientes por si se desea realizar un cierre permanente con tornillería pasante en el futuro.
- En caso de deslizamiento, se sugiere añadir/sustituir material antideslizante en el extremo de cada pata.

*Para extraer las pilas fácilmente, se aconseja que el chasis en el futuro sea diseñado con un sistema de apertura rápida.

*El procedimiento de reparación consiste en desatornillar el servo de su posición, desatornillar la tapa trasera del servo, recolocar el pequeño engranaje plástico en su pasador original, comprobar el giro manual y volver a sellar la carcasa.

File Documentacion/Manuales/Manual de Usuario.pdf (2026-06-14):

## Manual de Usuario

Este manual describe los procedimientos operativos estándar para garantizar el uso correcto y seguro del cuadrúpedo robótico.

### 0. Acceso a la Documentación Digital (Smart Tag NFC)

El chasis del cuadrúpedo está equipado con una etiqueta inteligente NFC pasiva ubicada en el lateral izquierdo de la caja de carga. Para acceder de forma instantánea al repositorio completo del proyecto (que incluye esta memoria técnica ampliada, el código fuente en Arduino, los esquemas de diseño, los scripts de simulación en Python…), simplemente acerque su dispositivo móvil con la función NFC activada a la pegatina.

### 1. Preparación previa:

- Sitúe el robot sobre una superficie plana, lisa y libre de obstáculos inmediatos.
- Asegúrese de que las extremidades se encuentran libres y no están enganchadas con ningún cableado interno.
- En caso de que lo desee, coloque la carga útil de 250 gramos exactamente sobre la caja hueca central del chasis (Centro de Gravedad) para evitar desequilibrios durante la marcha.

### 2. Secuencia de Encendido Seguro (Protocolo de Aislamiento) Para evitar picos de

tensión, siga este orden estricto:

1. Encendido Lógico: Conecte el cable USB del Arduino al Powerbank de 5V (si no está ya conectado). En caso de estar apagada la Powerbank, enciéndela en el botón de sí misma. En caso de tenerlo, verifique que el LED verde del semáforo de estado se ilumina, indicando el estado de "Despejado".
2. Encendido de Potencia: En caso de que no lo esté (caso raro), conecte el portapilas de las baterías 18650 (7.4V) a la bornera verde del controlador PCA9685, necesitarás un destornillador. Escuchará un leve zumbido indicando que los motores MG90S tienen fuerza de retención.
3. Cierre de chasis: En caso de necesitar cambiar las pilas o conectar algún cable, necesitará reponer las bridas que se quitaron para su apertura o volver a atornillar los tornillos, según prefiera el usuario.

### 3. Operación y Marcha

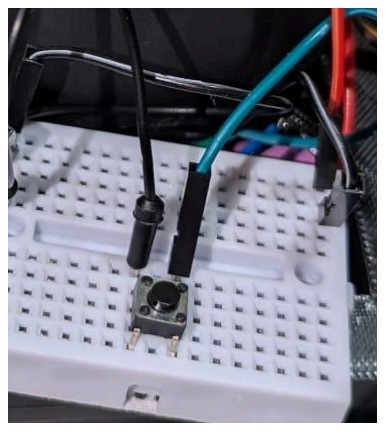
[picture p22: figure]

- Pulse el botón de inicio una sola vez.

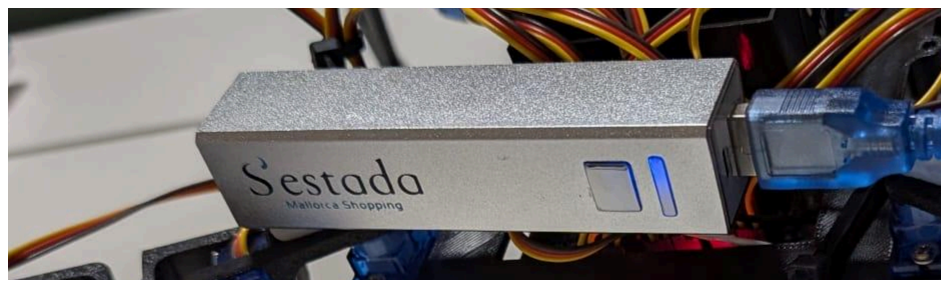
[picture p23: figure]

- El robot iniciará automáticamente la secuencia de marcha con movimiento de las patas en línea recta.
- Parada de emergencia: En caso de desequilibrio o riesgo de caída, pulse nuevamente el botón para volver al estado de reposo.

### 4. Secuencia de Apagado

Pulse en cualquier momento el botón para volver al estado de reposo. Desconecte el cable USB del Powerbank. Es buena práctica desconectar las baterías 18650.

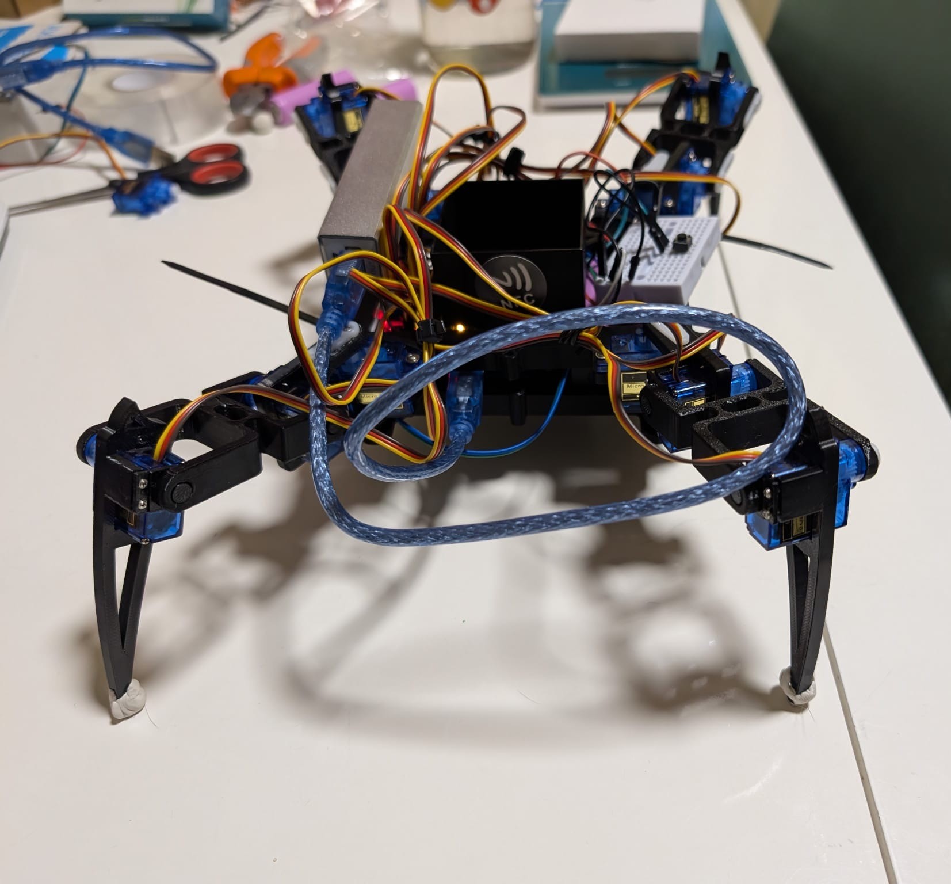
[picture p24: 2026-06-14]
Media/Fotos/MontajeLateral.JPG

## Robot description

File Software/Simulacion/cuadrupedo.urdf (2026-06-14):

<?xml version="1.0"?>
<robot name="robot_cuadrupedo">

  <material name="azul"><color rgba="0.1 0.4 0.8 1.0"/></material>
  <material name="rojo"><color rgba="0.8 0.1 0.1 1.0"/></material>
  <material name="negro"><color rgba="0.15 0.15 0.15 1.0"/></material>

  <link name="base_link">
    <inertial>
      <mass value="0.550"/>
      <inertia ixx="0.001" ixy="0.0" ixz="0.0" iyy="0.002" iyz="0.0" izz="0.002"/>
    </inertial>
    <visual>
      <geometry><box size="0.20 0.12 0.05"/></geometry>
      <material name="azul"/>
    </visual>
    <collision>
      <geometry><box size="0.20 0.12 0.05"/></geometry>
    </collision>
  </link>

  <link name="delantera_derecha_thigh">
    <inertial>
      <mass value="0.015"/>
      <inertia ixx="0.0001" ixy="0.0" ixz="0.0" iyy="0.0001" iyz="0.0" izz="0.0001"/>
    </inertial>
    <visual>
      <origin xyz="0 0 -0.025" rpy="0 0 0"/>
      <geometry><cylinder radius="0.01" length="0.05"/></geometry>
      <material name="negro"/>
    </visual>
    <collision>
      <origin xyz="0 0 -0.025" rpy="0 0 0"/>
      <geometry><cylinder radius="0.01" length="0.05"/></geometry>
    </collision>
  </link>

  <joint name="base_to_delantera_derecha_thigh" type="revolute">
    <parent link="base_link"/>
    <child link="delantera_derecha_thigh"/>
    <origin xyz="0.08 -0.07 0" rpy="0 0 -0.7854"/>
    <axis xyz="0 1 0"/>
    <limit lower="-1.57" upper="1.57" effort="0.215" velocity="6.0"/>
  </joint>

  <link name="delantera_derecha_tibia">
    <inertial>
      <mass value="0.015"/>
      <inertia ixx="0.0001" ixy="0.0" ixz="0.0" iyy="0.0001" iyz="0.0" izz="0.0001"/>
    </inertial>
    <visual>
      <origin xyz="0 0 -0.025" rpy="0 0 0"/>
      <geometry><cylinder radius="0.008" length="0.05"/></geometry>
      <material name="rojo"/>
    </visual>
    <collision>
      <origin xyz="0 0 -0.025" rpy="0 0 0"/>
      <geometry><cylinder radius="0.008" length="0.05"/></geometry>
    </collision>
  </link>

  <joint name="delantera_derecha_thigh_to_tibia" type="revolute">
    <parent link="delantera_derecha_thigh"/>
    <child link="delantera_derecha_tibia"/>
    <origin xyz="0 0 -0.05" rpy="0 0 0"/>
    <axis xyz="0 1 0"/>
    <limit lower="-1.57" upper="1.57" effort="0.215" velocity="6.0"/>
  </joint>

  <link name="delantera_izquierda_thigh">
    <inertial>
      <mass value="0.015"/>
      <inertia ixx="0.0001" ixy="0.0" ixz="0.0" iyy="0.0001" iyz="0.0" izz="0.0001"/>
    </inertial>
    <visual>
      <origin xyz="0 0 -0.025" rpy="0 0 0"/>
      <geometry><cylinder radius="0.01" length="0.05"/></geometry>
      <material name="negro"/>
    </visual>
    <collision>
      <origin xyz="0 0 -0.025" rpy="0 0 0"/>
      <geometry><cylinder radius="0.01" length="0.05"/></geometry>
    </collision>
  </link>

  <joint name="base_to_delantera_izquierda_thigh" type="revolute">
    <parent link="base_link"/>
    <child link="delantera_izquierda_thigh"/>
    <origin xyz="0.08 0.07 0" rpy="0 0 0.7854"/>
    <axis xyz="0 1 0"/>
    <limit lower="-1.57" upper="1.57" effort="0.215" velocity="6.0"/>
  </joint>

  <link name="delantera_izquierda_tibia">
    <inertial>
      <mass value="0.015"/>
      <inertia ixx="0.0001" ixy="0.0" ixz="0.0" iyy="0.0001" iyz="0.0" izz="0.0001"/>
    </inertial>
    <visual>
      <origin xyz="0 0 -0.025" rpy="0 0 0"/>
      <geometry><cylinder radius="0.008" length="0.05"/></geometry>
      <material name="rojo"/>
    </visual>
    <collision>
      <origin xyz="0 0 -0.025" rpy="0 0 0"/>
      <geometry><cylinder radius="0.008" length="0.05"/></geometry>
    </collision>
  </link>

  <joint name="delantera_izquierda_thigh_to_tibia" type="revolute">
    <parent link="delantera_izquierda_thigh"/>
    <child link="delantera_izquierda_tibia"/>
    <origin xyz="0 0 -0.05" rpy="0 0 0"/>
    <axis xyz="0 1 0"/>
    <limit lower="-1.57" upper="1.57" effort="0.215" velocity="6.0"/>
  </joint>

  <link name="trasera_derecha_thigh">
    <inertial>
      <mass value="0.015"/>
      <inertia ixx="0.0001" ixy="0.0" ixz="0.0" iyy="0.0001" iyz="0.0" izz="0.0001"/>
    </inertial>
    <visual>
      <origin xyz="0 0 -0.025" rpy="0 0 0"/>
      <geometry><cylinder radius="0.01" length="0.05"/></geometry>
      <material name="negro"/>
    </visual>
    <collision>
      <origin xyz="0 0 -0.025" rpy="0 0 0"/>
      <geometry><cylinder radius="0.01" length="0.05"/></geometry>
    </collision>
  </link>

  <joint name="base_to_trasera_derecha_thigh" type="revolute">
    <parent link="base_link"/>
    <child link="trasera_derecha_thigh"/>
    <origin xyz="-0.08 -0.07 0" rpy="0 0 -2.3562"/>
    <axis xyz="0 1 0"/>
    <limit lower="-1.57" upper="1.57" effort="0.215" velocity="6.0"/>
  </joint>

  <link name="trasera_derecha_tibia">
    <inertial>
      <mass value="0.015"/>
      <inertia ixx="0.0001" ixy="0.0" ixz="0.0" iyy="0.0001" iyz="0.0" izz="0.0001"/>
    </inertial>
    <visual>
      <origin xyz="0 0 -0.025" rpy="0 0 0"/>
      <geometry><cylinder radius="0.008" length="0.05"/></geometry>
      <material name="rojo"/>
    </visual>
    <collision>
      <origin xyz="0 0 -0.025" rpy="0 0 0"/>
      <geometry><cylinder radius="0.008" length="0.05"/></geometry>
    </collision>
  </link>

  <joint name="trasera_derecha_thigh_to_tibia" type="revolute">
    <parent link="trasera_derecha_thigh"/>
    <child link="trasera_derecha_tibia"/>
    <origin xyz="0 0 -0.05" rpy="0 0 0"/>
    <axis xyz="0 1 0"/>
    <limit lower="-1.57" upper="1.57" effort="0.215" velocity="6.0"/>
  </joint>

  <link name="trasera_izquierda_thigh">
    <inertial>
      <mass value="0.015"/>
      <inertia ixx="0.0001" ixy="0.0" ixz="0.0" iyy="0.0001" iyz="0.0" izz="0.0001"/>
    </inertial>
    <visual>
      <origin xyz="0 0 -0.025" rpy="0 0 0"/>
      <geometry><cylinder radius="0.01" length="0.05"/></geometry>
      <material name="negro"/>
    </visual>
    <collision>
      <origin xyz="0 0 -0.025" rpy="0 0 0"/>
      <geometry><cylinder radius="0.01" length="0.05"/></geometry>
    </collision>
  </link>

  <joint name="base_to_trasera_izquierda_thigh" type="revolute">
    <parent link="base_link"/>
    <child link="trasera_izquierda_thigh"/>
    <origin xyz="-0.08 0.07 0" rpy="0 0 2.3562"/>
    <axis xyz="0 1 0"/>
    <limit lower="-1.57" upper="1.57" effort="0.215" velocity="6.0"/>
  </joint>

  <link name="trasera_izquierda_tibia">
    <inertial>
      <mass value="0.015"/>
      <inertia ixx="0.0001" ixy="0.0" ixz="0.0" iyy="0.0001" iyz="0.0" izz="0.0001"/>
    </inertial>
    <visual>
      <origin xyz="0 0 -0.025" rpy="0 0 0"/>
      <geometry><cylinder radius="0.008" length="0.05"/></geometry>
      <material name="rojo"/>
    </visual>
    <collision>
      <origin xyz="0 0 -0.025" rpy="0 0 0"/>
      <geometry><cylinder radius="0.008" length="0.05"/></geometry>
    </collision>
  </link>

  <joint name="trasera_izquierda_thigh_to_tibia" type="revolute">
    <parent link="trasera_izquierda_thigh"/>
    <child link="trasera_izquierda_tibia"/>
    <origin xyz="0 0 -0.05" rpy="0 0 0"/>
    <axis xyz="0 1 0"/>
    <limit lower="-1.57" upper="1.57" effort="0.215" velocity="6.0"/>
  </joint>
</robot>

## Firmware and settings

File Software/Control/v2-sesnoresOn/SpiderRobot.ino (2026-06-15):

#include <Wire.h>
#include <Adafruit_PWMServoDriver.h>

Adafruit_PWMServoDriver pca = Adafruit_PWMServoDriver(0x40);
volatile boolean sistemaPausado = true;

#include "config.h"
#include "sensor.h"
#include "steps.h"

unsigned long ultimoTiempoBoton = 0;

void comprobarBotonPausa() {
  // Leemos si el botón ha sido pulsado
  if (digitalRead(pinBoton) == LOW) {
    // Si han pasado más de 300ms desde el último toque (evita dobles lecturas)
    if (millis() - ultimoTiempoBoton > 300) {
      sistemaPausado = !sistemaPausado; // Cambiamos el estado al instante
      ultimoTiempoBoton = millis(); // Guardamos el momento del toque
      if (sistemaPausado) {
        Serial.println("\n========= SISTEMA PAUSADO =========");
        // TRUCO: Despausamos temporalmente a nivel interno para que el robot
        // pueda usar la interpolación de ponerse firme, y luego lo volvemos a pausar.
        sistemaPausado = false;
        standPose();
        sistemaPausado = true;
      } else {
        Serial.println("\n========= SISTEMA INICIADO =========");
      }
    }
  }
}

void setup() {
Serial.begin(115200);
Wire.begin();

pca.begin();
pca.setPWMFreq(50); // Mantenemos 50Hz, la frecuencia perfecta para MG90S

// ========================================================
// ¡AQUÍ ESTÁ EL SECRETO DE LA FLUIDEZ!
// Cargamos los ángulos iniciales en la memoria antes de mover
// ========================================================
iniciarInterpolador();

configurarSensores();

pinMode(pinBoton, INPUT_PULLUP);

Serial.println("=============================================");
Serial.println(" ESPERANDO PULSACION DEL BOTON PARA INICIAR ");
Serial.println("=============================================");

// Se pone de pie de forma súper suave usando la nueva función
sistemaPausado = false;
standPose();
sistemaPausado = true;
}

void loop() {
  comprobarBotonPausa();

  // Si está pausado, no hace nada, solo espera al botón
  if (sistemaPausado) {
    delay(100);
    return;
  }

  // --- LÓGICA DE DETECCIÓN Y SEGURIDAD ---
  int distanciaFrente = obtenerDistancia(triggerFrente, echoFrente, "Frente");

  // REGLA 1: Emergencia - Si está a 5 cm o menos de la pared
  if (distanciaFrente <= 6) {
    Serial.println("\n[¡ALERTA!] ¡Pared demasiado cerca! Parada de emergencia.");
    encenderSoloLed(ledRojo); // Mantenemos el rojo encendido
    
    // Hacemos que el robot se ponga firme de forma suave antes de pausar
    standPose(); 
    sistemaPausado = true; // Pausamos el sistema automáticamente
    return; // Salimos del loop para que no intente dar el siguiente paso
  }
  
  // REGLA 2: Aviso - Si está a 15 cm o menos de la pared
  else if (distanciaFrente <= 15) {
    encenderSoloLed(ledRojo); // Encendemos ROJO (Pared detectada)
  } 
  
  // REGLA 3: Camino libre
  else {
    encenderSoloLed(ledVerde); // Encendemos VERDE (Todo despejado)
  }

  // Ejecuta la marcha de gateo fluida
  avanzarPaso();
}

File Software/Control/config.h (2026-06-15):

#ifndef CONFIG_H
#define CONFIG_H

const int triggerFrente = 2;
const int echoFrente = 3;
const int triggerIzquierda = 4;
const int echoIzquierda = 5;

const int pinBoton = 9;
const int ledRojo = 6;
const int ledAmarillo = 7;
const int ledVerde = 8;

const int DIST_OBSTACULO_FRENTE = 25;
const int PARED_IDEAL_IZQ = 20;
const int MARGEN_PARED = 5;

const int SERVO_MIN = 110;
const int SERVO_MAX = 510;

const int FL[3] = {1, 0, 2};
const int FR[3] = {4, 3, 5};
const int BL[3] = {7, 6, 8};
const int BR[3] = {9, 10, 11};

int center[12] = {
  90, 90, 90,
  90, 90, 90,
  90, 90, 90,
  90, 90, 90
};

int dir[12] = {
  1, -1, 1,
 -1, 1, -1,
 -1, -1, -1,
  1, 1, 1
};

const int HIP_SWING = 20;
const int SHOULDER_LIFT = 15;
const int KNEE_BEND = 35;

const int STEP_DELAY = 200;
const int STEP_SETTLE = 250;

const char* nombres[4] = {
  "FL (Del. Izq)",
  "FR (Del. Der)",
  "BL (Tras. Izq)",
  "BR (Tras. Der)"
};

extern volatile boolean sistemaPausado;

#endif

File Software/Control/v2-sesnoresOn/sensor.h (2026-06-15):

#ifndef SENSOR_H
#define SENSOR_H

#include <Arduino.h>
#include "config.h"

void configurarSensores() {
  pinMode(triggerFrente, OUTPUT);
  pinMode(echoFrente, INPUT);
  //pinMode(triggerIzquierda, OUTPUT);
  //pinMode(echoIzquierda, INPUT);

  pinMode(pinBoton, INPUT_PULLUP);

  pinMode(ledRojo, OUTPUT);
  //pinMode(ledAmarillo, OUTPUT);
  pinMode(ledVerde, OUTPUT);

  // Apagamos todos los leds al iniciar
  digitalWrite(ledRojo, LOW);
  //digitalWrite(ledAmarillo, LOW);
  digitalWrite(ledVerde, LOW);
}

void encenderSoloLed(int ledEncender) {
  digitalWrite(ledRojo, ledEncender == ledRojo ? HIGH : LOW);
  //digitalWrite(ledAmarillo, ledEncender == ledAmarillo ? HIGH : LOW);
  digitalWrite(ledVerde, ledEncender == ledVerde ? HIGH : LOW);
}

int obtenerDistancia(int trigPin, int echoPin, const char* nombreSensor) {
  digitalWrite(trigPin, LOW);
  delayMicroseconds(2);
  digitalWrite(trigPin, HIGH);
  delayMicroseconds(10);
  digitalWrite(trigPin, LOW);

  long duracion = pulseIn(echoPin, HIGH);
  int distancia = duracion * 0.034 / 2;

  Serial.print("[SENSOR] ");
  Serial.print(nombreSensor);
  Serial.print(" -> Tiempo de Eco: ");
  Serial.print(duracion);
  Serial.print(" us | Distancia: ");
  Serial.print(distancia);
  Serial.println(" cm");

  if (distancia == 0 || distancia > 350) {
    return 400;
  }

  return distancia;
}

#endif
